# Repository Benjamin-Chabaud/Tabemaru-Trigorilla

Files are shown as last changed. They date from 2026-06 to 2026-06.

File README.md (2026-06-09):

# Tabemaru Control Board

## Overview
This repository contains the firmware (`tabemaru-V5-verbose.ino`) and documentation for the **Tabemaru Control Board**. The system is built around an Arduino Mega 2560 architecture (specifically using an Anycubic Trigorilla motherboard) combined with a custom PCB.

The system is designed to automate a sequence involving valves, a motor, and a heated bed, while continuously logging environmental data (temperature and humidity) to both a Serial Monitor and an SD Card in a non-blocking manner.

## Firmware Logic Explanation
The firmware is built using a non-blocking architecture, utilizing `millis()` to manage multiple tasks simultaneously without halting the processor. 

### 1. The Operational Sequence
The core logic of the machine relies on a 4-step state machine triggered by a hardware button (Button X-).
*   **Step 1 (Valve 1):** The sequence begins, the hotbed turns on, and Valve 1 opens for `1m 40s`.
*   **Step 2 (Motor):** Valve 1 closes, and the Motor runs for `5s`.
*   **Step 3 (Valve 2):** The motor stops, and Valve 2 opens for `2m 20s`.
*   **Step 4 (Wait & Hotbed):** Valve 2 closes. The system waits until the total elapsed time reaches `800s`. During this entire 800-second sequence, the heated bed actively regulates its temperature. Once 800 seconds pass, the sequence automatically terminates and resets.

*Note: All timings are defined as constants at the top of the code and can be easily modified.*

### 2. Hardware Interrupts
To ensure zero-latency responsiveness, the physical buttons do not use standard `digitalRead()` polling. Instead, they use Hardware Interrupts (`attachInterrupt`). 
*   **X- Button (Sequence Start/Stop):** Reacts instantly to start the sequence or act as an emergency stop.
*   **Z- Button (LED / SD Eject):** A short press toggles the internal LED. Holding the button for 1.5 seconds safely ejects the SD card (suspends writing) or remounts it.

### 3. SD Card & Data Storage
The system logs data in CSV format. It features a robust **Hot-Swap background task**. If the SD card is removed (or communication fails due to interference), the system will safely catch the error and attempt to re-initialize the SD card every 10 seconds. When the card is reinserted, data logging resumes automatically.

**SD Card Requirements & Formatting:**
For the SD card module to work reliably with the Arduino architecture, the following requirements MUST be met:
*   **Capacity:** 8GB is highly recommended for maximum stability (though up to 32GB SDHC is technically supported). SDXC cards (64GB+) will not work.
*   **File System:** The card MUST be formatted in **FAT32** (or FAT16). exFAT, NTFS, or APFS are not supported by the standard Arduino library.
*   **Formatting Tool & Deep Reset:** It is strongly advised to use the official SD Association's *SD Memory Card Formatter*. If the Arduino fails to initialize the card, a standard "Quick Format" is often not enough. You must select **"Overwrite Format"** (Full Format) to completely wipe the flash memory sectors and rebuild the file system from scratch.
*   **Partition Scheme:** The card's partition map MUST be **MBR (Master Boot Record)**. If the card was previously formatted on a Mac or newer OS as GPT (GUID Partition Table), the Arduino will fail to read it. To fix this, the partition table must be completely wiped (e.g., using `diskpart > clean` on Windows) before reformatting to FAT32.
*   **File Naming:** The system writes to `LOG.CSV`, strictly adhering to the legacy 8.3 filename convention.

**Data Storage Capacity & Retention:**
At the current logging rate (one entry every 2 seconds), the system generates approximately 1.2 GB of CSV data per year of continuous 24/7 operation. An 8GB SD card (the recommended maximum size for optimal compatibility) can hold data for **over 5 years** before running out of space. 

Depending on your operational needs, you can either:
*   Safely eject the SD card every few years to manually archive and delete the data.
*   Modify the logging function in the firmware to implement a rolling log (automatically deleting the oldest data when space runs out).

**Hardware & Operational Recommendations:**
*   **Logic Level Shifting:** The Arduino outputs 5V logic, but SD cards strictly require 3.3V. Ensure your SD card reader module has a built-in logic level converter chip and a 3.3V voltage regulator. Direct 5V connections will damage the SD card and cause instability.
*   **Cable Length & Interference:** The SPI protocol is highly susceptible to electromagnetic interference (EMI). Keep the SPI cables (MISO, MOSI, SCK) as short as possible and route them away from high-power cables (like the hotbed heater or motor).
*   **Flash Wear-Leveling:** Since the system writes data continuously (24/7), standard consumer SD cards may suffer from premature flash memory degradation. It is highly recommended to use a **"High Endurance"** SD card (typically used for dashcams or security cameras) designed for continuous write operations.

### 4. Environmental Monitoring & Thermostat
*   **DHT20 Sensors:** Two I2C temperature/humidity sensors are routed through a **TCA9548A Multiplexer**. They are polled every 2 seconds.
*   **Thermostat:** The system reads an NTC 100k thermistor connected to analog pin `A15` (Port T2) and uses the Steinhart-Hart equation to calculate temperature in Celsius. It maintains a target temperature of 105°C using a 1°C hysteresis.
*   **OLED Display:** A 128x32 OLED display provides real-time feedback on sequence state, actuator status, SD card health, and sensor readings.

---

## Custom PCB Analysis (KiCad)

The custom "Tabemaru control board" acts as an intermediate shield/routing board that neatly bridges the Trigorilla motherboard with the external peripherals, and also acts as a Human-Machine Interface (HMI).

### Schematic Details
1.  **I2C Multiplexer (TCA9548A):**
    *   Connectors `J1` and `J6` are designed to host a TCA9548A multiplexer breakout board. 
    *   The `sda` and `scl` lines from the Trigorilla input are fed into the multiplexer.
    *   The multiplexer outputs channels `sd1/sc1` and `sd2/sc2` to split the I2C bus, allowing two identical DHT20 sensors (which have the same hardcoded I2C address) to operate simultaneously.
2.  **DHT20 Sensor Headers:**
    *   `J2` and `J3` connect to the Top and Bottom DHT20 sensors. They receive the separated I2C channels from the multiplexer alongside VCC and GND.
3.  **Trigorilla Interconnect (`J4`):**
    *   This 6-pin connector bridges the custom PCB back to the main Trigorilla board. It carries the primary I2C bus (`sda`, `scl`), Ground, VCC, and the two button signals (`bp1`, `bp2`).
4.  **OLED Screen Header (`J5`):**
    *   This 10-pin header routes `VCC`, `GND`, `sda`, and `scl` directly to the OLED screen. Notes indicate that `sc1` and `sd1` are connected just to physically route them through the connector, though they are not utilized by the screen itself.
5.  **User Inputs (Buttons):**
    *   `SW1` and `SW2` are tactile push buttons that pull the `bp1` and `bp2` lines to Ground when pressed. These correspond to the X- and Z- endstop logic in the code.
6.  **Power Delivery & Decoupling:**
    *   Capacitors `C1`, `C2`, `C3`, `C4` are placed across the VCC and GND lines to stabilize the power delivery to the sensors and ICs, preventing voltage drops and filtering out electrical noise.

### PCB Layout Notes
*   The PCB is a two-layer board (Top Copper in Red, Bottom Copper in Blue). Both sides are identical and interconnected so that the connectors can be mounted on either side depending on the final position of the board inside the composter. Although this makes the routing technically less optimized (for instance, a VCC line making a half-loop is not ideal), it provides necessary mechanical flexibility for prototyping.
*   Thick traces are used for the main VCC and GND rails to ensure stable current delivery, while thinner traces are used for data lines (`sda`, `scl`).
*   The design elegantly centralizes all messy external wiring (buttons, screen, sensors) into a single, clean interface board that connects directly to the Trigorilla via the `J4` header.

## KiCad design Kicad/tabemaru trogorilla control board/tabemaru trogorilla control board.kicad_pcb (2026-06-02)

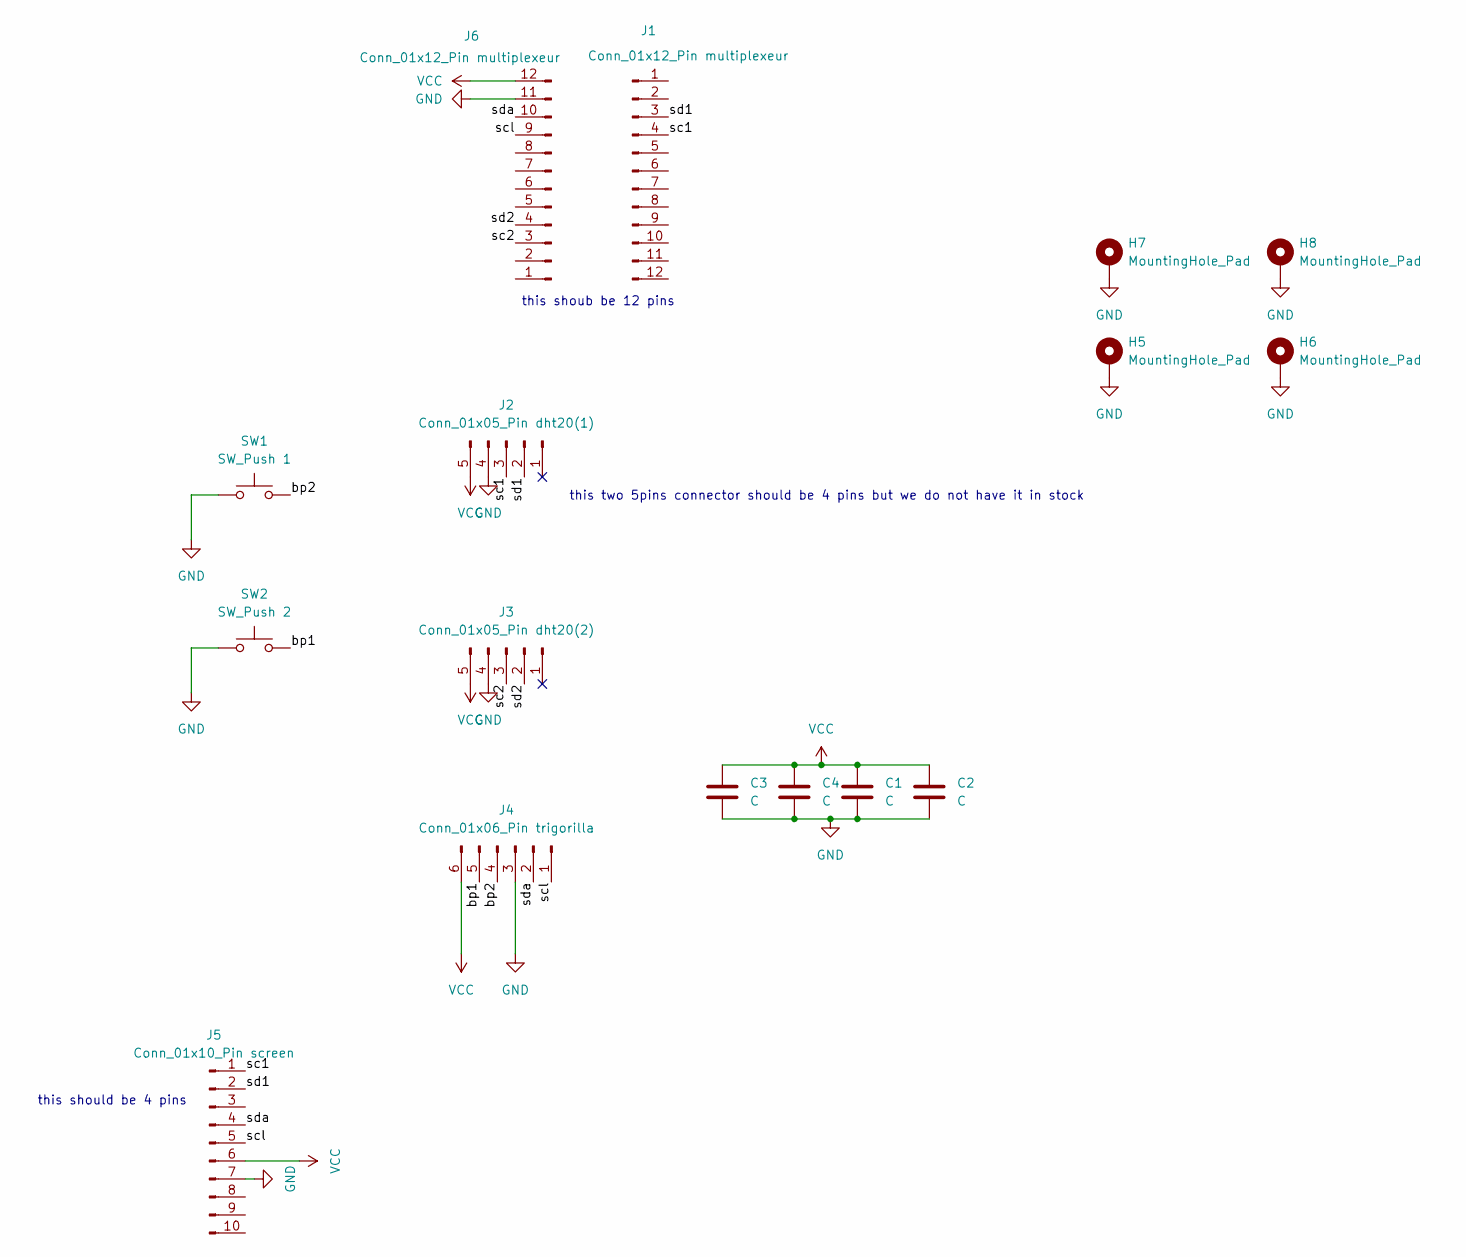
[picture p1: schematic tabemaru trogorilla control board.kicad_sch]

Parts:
C1, C2, C3, C4: C; PinHeader_1x02_P2.54mm_Vertical
H5, H6, H7, H8: MountingHole_Pad; MountingHole_3.5mm_Pad
J1, J6: Conn_01x12_Pin multiplexeur; PinHeader_1x12_P2.54mm_Vertical
J2: Conn_01x05_Pin dht20(1); JST_XH_B5B-XH-A_1x05_P2.50mm_Vertical
J3: Conn_01x05_Pin dht20(2); JST_XH_B5B-XH-A_1x05_P2.50mm_Vertical
J4: Conn_01x06_Pin trigorilla; JST_XH_B6B-XH-A_1x06_P2.50mm_Vertical
J5: Conn_01x10_Pin screen; PinHeader_1x10_P2.54mm_Vertical
SW1: SW_Push 1; SW_PUSH_6mm_H4.3mm
SW2: SW_Push 2; SW_PUSH_6mm_H4.3mm

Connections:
/bp1: J4.5, SW2.2
/bp2: J4.4, SW1.2
/sc1: J1.4, J2.3, J5.1
/sc2: J3.3, J6.3
/scl: J4.1, J5.5, J6.9
/sd1: J1.3, J2.2, J5.2
/sd2: J3.2, J6.4
/sda: J4.2, J5.4, J6.10
GND: C1.2, C2.2, C3.2, C4.2, H5.1 (1_1), H6.1 (1_1), H7.1 (1_1), H8.1 (1_1), J2.4, J3.4, J4.3, J5.7, J6.11, SW1.1, SW2.1
VCC: C1.1, C2.1, C3.1, C4.1, J2.5, J3.5, J4.6, J5.6, J6.12

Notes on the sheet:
this should be 4 pins
this shoub be 12 pins
this two 5pins connector should be 4 pins but we do not have it in stock

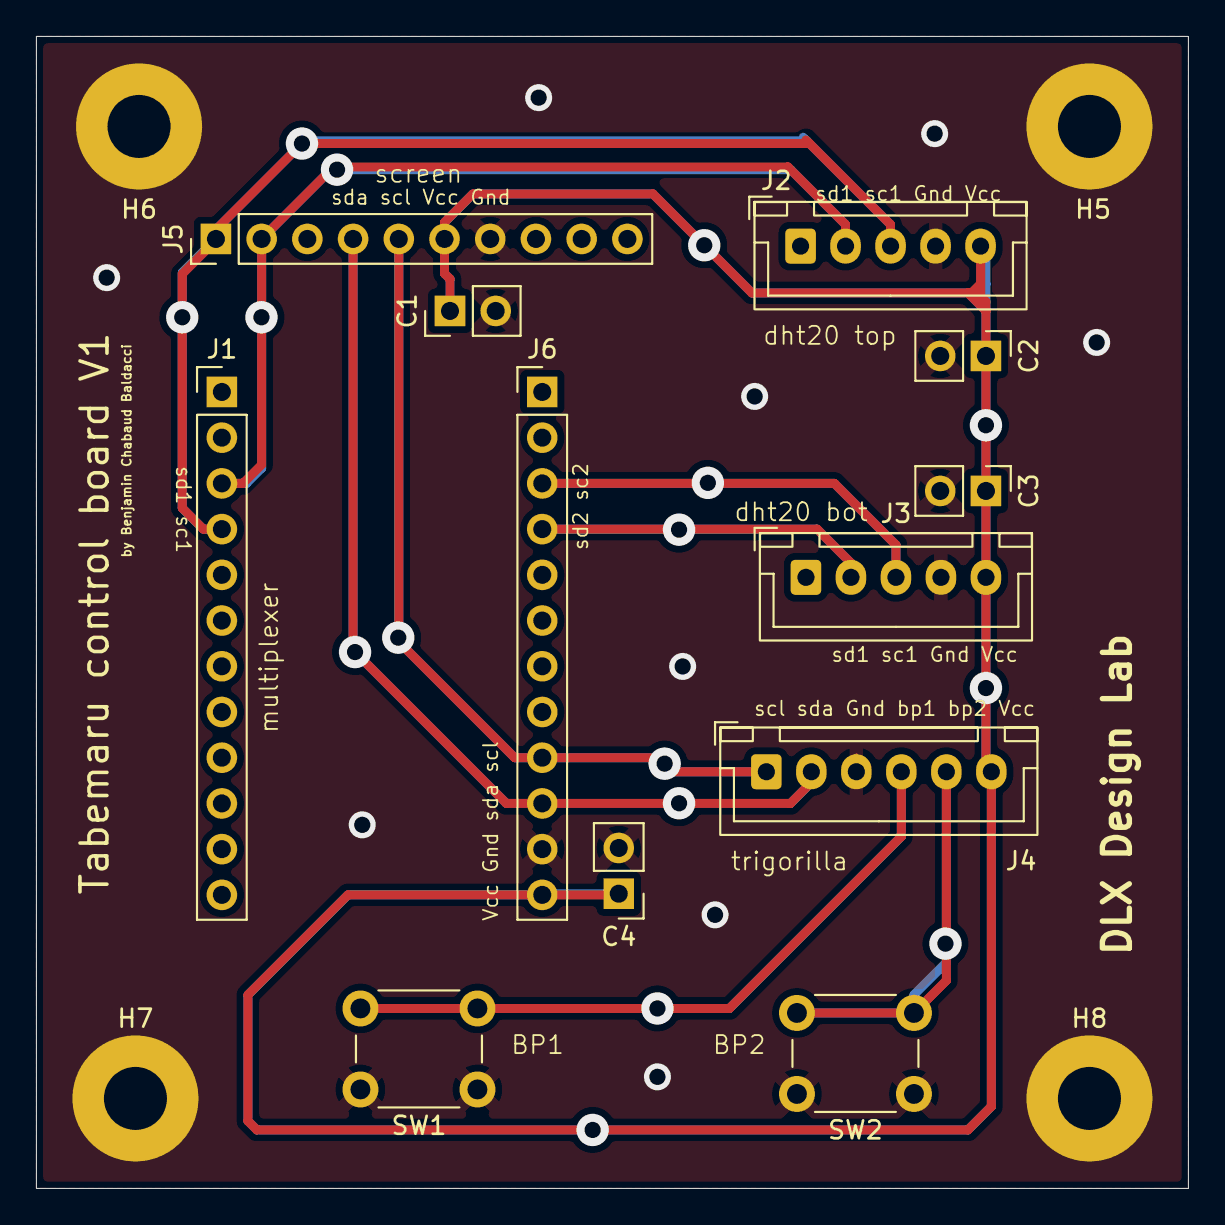
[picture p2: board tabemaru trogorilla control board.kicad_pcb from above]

Board: 2 copper layers, 64.0 x 64.0 mm, 16 parts (0 on the bottom side), 10 nets.

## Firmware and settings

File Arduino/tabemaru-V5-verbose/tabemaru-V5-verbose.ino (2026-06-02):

#include <Wire.h>
#include "DHT20.h"
#include <Adafruit_GFX.h>
#include <Adafruit_SSD1306.h>
#include <SPI.h>
#include <SD.h>

// --- SENSOR OBJECTS ---
// Two DHT20 temperature and humidity sensors
DHT20 dhtTop;
DHT20 dhtBot;

// --- I2C MULTIPLEXER (TCA9548A) CONTROL ---
// The multiplexer allows multiple I2C devices with the same address to coexist on the bus.
#define TCAADDR 0x70

// Function to switch the active channel on the I2C multiplexer
void tcaSelect(uint8_t i) {
  if (i > 7) return; // The TCA9548A only has 8 channels (0 to 7)
  Wire.beginTransmission(TCAADDR);
  Wire.write(1 << i);
  Wire.endTransmission();
  delay(10); // Short delay to ensure the switch is completed before communication
}

// --- OLED DISPLAY DEFINITIONS ---
#define SCREEN_WIDTH 128
#define SCREEN_HEIGHT 32
#define OLED_RESET    -1 // -1 means the display shares the Arduino reset pin
#define SCREEN_ADDRESS 0x3C // Default I2C address for 128x32 SSD1306 OLEDs
Adafruit_SSD1306 display(SCREEN_WIDTH, SCREEN_HEIGHT, &Wire, OLED_RESET);

// --- SD CARD DEFINITIONS ---
const int chipSelect = 53; // SPI Chip Select (CS) pin for the SD card reader on Trigorilla (Mega 2560)
bool sdReady = false;      // Flag indicating if the SD card is successfully initialized and ready
bool safeToEject = false;  // Flag indicating if the user requested to safely eject the SD card

// --- PIN DEFINITIONS (TRIGORILLA BOARD) ---
const int buttonXMinPin = 3;  // Sequence start button (connected to X- endstop pin)
const int buttonZMinPin = 18; // LED toggle and SD eject button (connected to Z- endstop pin)
const int motorPin  = 9;      // Motor control pin
const int valve1Pin = 7;      // First valve control pin
const int valve2Pin = 44;     // Second valve control pin
const int ledPin    = 10;     // Internal illumination LED control pin
const int hotbedPin = 8;      // Hotbed heating element control pin
const int bedTempPin = A15;   // Hotbed thermistor analog input pin (T2 port)

// --- TIMERS FOR NON-BLOCKING DELAYS ---
// We use millis() instead of delay() so the program never freezes
unsigned long previousLcdMillis = 0;
const long lcdInterval = 250;  // Refresh OLED every 250ms
unsigned long previousTempMillis = 0;
const long tempInterval = 500; // Read hotbed temperature every 500ms
unsigned long previousDHTMillis = 0;
const long dhtInterval = 2000; // Read DHT20 sensors every 2000ms (2 seconds)
unsigned long previousSDMillis = 0;
const long sdInterval = 10000; // Attempt SD card reconnection every 10 seconds

// --- SEQUENCE TIMINGS (in milliseconds) ---
const unsigned long timeValve1 = 100000; // Step 1: Valve 1 remains open for 1 minute and 40 seconds
const unsigned long timeMotor  = 5000;   // Step 2: Motor runs for 5 seconds
const unsigned long timeValve2 = 140000; // Step 3: Valve 2 remains open for 2 minutes and 20 seconds
const unsigned long timeHotbed = 800000; // Total hotbed activation time, which also dictates the end of the entire sequence

// --- STATE MEMORY ---
bool ledState = LOW;                  // Current state of the illumination LED
int sequenceState = 0;                // Current step of the operational sequence (0 = Idle, 1-4 = Active)
unsigned long sequenceStartTime = 0;  // Timestamp when the sequence was started

// --- HARDWARE INTERRUPT VARIABLES ---
// Using volatile variables because they are modified inside Interrupt Service Routines (ISRs)
volatile unsigned long xFallTime = 0;
volatile bool flagXPressed = false;   // Flag raised when the X button is pressed

volatile unsigned long zFallTime = 0;
volatile bool zCurrentlyPressed = false; // Real-time state of the Z button
volatile bool zStateChanged = false;     // Flag raised when the Z button state changes
bool longPressHandled = false;           // Prevents multiple triggers for a single long press
const unsigned long LONG_PRESS_TIME = 1500; // Holding Z button for 1.5 seconds triggers SD Eject

// Interrupt Service Routine for Button X (Sequence Start)
void isr_X() {
  if (millis() - xFallTime > 200) { // Software debounce: ignore signals closer than 200ms
    flagXPressed = true;
    xFallTime = millis();
  }
}

// Interrupt Service Routine for Button Z (LED Toggle / SD Eject)
void isr_Z() {
  bool st = digitalRead(buttonZMinPin);
  zCurrentlyPressed = (st == LOW); // LOW means the button is pressed (INPUT_PULLUP logic)
  if (zCurrentlyPressed) {
    zFallTime = millis(); // Record the exact time the button was pressed down
  }
  zStateChanged = true;
}

// --- THERMOSTAT VARIABLES ---
const float targetTemp = 105.0; // Target temperature for the hotbed in Celsius
const float hysteresis = 1.0;   // Allowable temperature drift before re-engaging the heater
bool regulateHotbed = false;    // Flag enabling the thermostat regulation logic
float currentBedTemp = 0.0;     // Last read temperature of the hotbed
bool isHeatingActive = false;   // Flag tracking if the heating element is currently ON

// Steinhart-Hart equation constants for 100k NTC Thermistor
const float R1 = 4700.0;   // Pull-up resistor on the Trigorilla board (4.7k Ohm)
const float R0 = 100000.0; // Nominal resistance of the thermistor at 25C (100k Ohm)
const float T0 = 298.15;   // Nominal temperature in Kelvin (25C)
const float B = 3950.0;    // Beta coefficient of the thermistor

// --- EVENT LOGGING FUNCTION ---
// Formats and outputs system state to both the Serial Monitor and the SD Card CSV file.
void logEvent(String eventName) {
  unsigned long currentMillis = millis();
  
  // Resolve boolean states for logging based on the current sequence step
  bool v1State = (sequenceState == 1);
  bool mState = (sequenceState == 2);
  bool v2State = (sequenceState == 3);
  bool hotbedState = (regulateHotbed && isHeatingActive);

  // 1. Output to Serial Monitor (Human-readable format)
  Serial.print("[LOG] Time: "); Serial.print(currentMillis);
  Serial.print(" | Event: "); Serial.print(eventName);
  Serial.print(" | Top: "); Serial.print(dhtTop.getTemperature(), 1); Serial.print("C/"); Serial.print(dhtTop.getHumidity(), 1); Serial.print("%");
  Serial.print(" | Bot: "); Serial.print(dhtBot.getTemperature(), 1); Serial.print("C/"); Serial.print(dhtBot.getHumidity(), 1); Serial.print("%");
  Serial.print(" | Bed: "); Serial.print(currentBedTemp, 1); Serial.print("C");
  Serial.print(" | SEQ: "); Serial.print(sequenceState);
  Serial.print(" | LED:"); Serial.print(ledState ? 1 : 0);
  Serial.print(" V1:"); Serial.print(v1State ? 1 : 0);
  Serial.print(" V2:"); Serial.print(v2State ? 1 : 0);
  Serial.print(" M:"); Serial.print(mState ? 1 : 0);
  Serial.print(" HB:"); Serial.println(hotbedState ? 1 : 0); 

  // 2. Output to SD Card (CSV format for data analysis)
  if (sdReady && !safeToEject) {
    File dataFile = SD.open("LOG.CSV", FILE_WRITE);
    if (dataFile) {
      dataFile.print(currentMillis); dataFile.print(",");
      dataFile.print(eventName); dataFile.print(",");
      dataFile.print(dhtTop.getTemperature(), 1); dataFile.print(",");
      dataFile.print(dhtTop.getHumidity(), 1); dataFile.print(",");
      dataFile.print(dhtBot.getTemperature(), 1); dataFile.print(",");
      dataFile.print(dhtBot.getHumidity(), 1); dataFile.print(",");
      dataFile.print(currentBedTemp, 1); dataFile.print(",");
      dataFile.print(sequenceState); dataFile.print(",");
      dataFile.print(ledState ? 1 : 0); dataFile.print(",");
      dataFile.print(v1State ? 1 : 0); dataFile.print(",");
      dataFile.print(v2State ? 1 : 0); dataFile.print(",");
      dataFile.print(mState ? 1 : 0); dataFile.print(",");
      dataFile.println(hotbedState ? 1 : 0); 
      
      dataFile.close();
    } else {
      // If the file fails to open, assume the SD card was abruptly removed
      sdReady = false;
      Serial.println("[CRITICAL ERROR] SD Card lost during event writing!");
    }
  }
}

// --- SETUP ROUTINE ---
// Runs once at power-on to initialize all hardware components.
void setup() {
  Serial.begin(115200);
  Serial.println("==================================");
  Serial.println("[SYSTEM] Booting up Tabemaru V5...");
  
  Serial.println("[SYSTEM] Initializing Actuator Pins...");
  // Configure output pins for relays, motor, and heating element
  pinMode(motorPin, OUTPUT);
  pinMode(valve1Pin, OUTPUT);
  pinMode(valve2Pin, OUTPUT);
  pinMode(ledPin, OUTPUT);
  pinMode(hotbedPin, OUTPUT);

  // Set initial safe states (everything OFF) without triggering log events yet
  regulateHotbed = false; 
  digitalWrite(hotbedPin, LOW); 
  digitalWrite(valve1Pin, LOW);
  digitalWrite(motorPin, LOW);
  digitalWrite(valve2Pin, LOW);
  sequenceState = 0; 
  isHeatingActive = false;
  
  digitalWrite(ledPin, LOW);

  // Configure input pins for buttons with internal pull-up resistors
  pinMode(buttonXMinPin, INPUT_PULLUP);
  pinMode(buttonZMinPin, INPUT_PULLUP);

  Serial.println("[SYSTEM] Attaching Hardware Interrupts...");
  // Attach interrupts for zero-latency button responses
  attachInterrupt(digitalPinToInterrupt(buttonXMinPin), isr_X, FALLING); // Triggers when pressed (HIGH to LOW)
  attachInterrupt(digitalPinToInterrupt(buttonZMinPin), isr_Z, CHANGE);  // Triggers on press and release

  Serial.println("[SYSTEM] Starting I2C Bus...");
  Wire.begin();
  
  // Initialize DHT20 Sensors through the multiplexer
  Serial.println("[SYSTEM] Initializing DHT20 Sensors...");
  tcaSelect(0); // Select multiplexer channel 0 for the top sensor
  if(dhtTop.begin()) { Serial.println("[SYSTEM] TOP DHT20 connected on SC0."); }
  else { Serial.println("[ERROR] TOP DHT20 failed to connect!"); }
  
  tcaSelect(3); // Select multiplexer channel 3 for the bottom sensor
  if(dhtBot.begin()) { Serial.println("[SYSTEM] BOTTOM DHT20 connected on SC3."); }
  else { Serial.println("[ERROR] BOTTOM DHT20 failed to connect!"); }
  
  // Initialize the OLED Display
  Serial.println("[SYSTEM] Initializing OLED Display...");
  if(!display.begin(SSD1306_SWITCHCAPVCC, SCREEN_ADDRESS)) {
    Serial.println("[ERROR] OLED Screen failed!");
  } else {
    display.clearDisplay();
    display.setTextSize(1);
    display.setTextColor(SSD1306_WHITE);
    display.setCursor(0,0);
    display.println("System Ready...");
    display.display();
    delay(500); // Briefly show the ready message
  }

  // Initialize the SD Card communication via SPI
  Serial.print("[SYSTEM] Initializing SD card...");
  pinMode(53, OUTPUT); // Hardware SS pin must be OUTPUT on Mega for SPI to work

  if (!SD.begin(chipSelect)) {
    Serial.println(" FAILED! (Will retry in background)");
    sdReady = false;
  } else {
    Serial.println(" OK!");
    sdReady = true;
    
    // Create or open the CSV file and write the header row if the file is new
    File dataFile = SD.open("LOG.CSV", FILE_WRITE);
    if (dataFile) {
      if (dataFile.size() == 0) {
        dataFile.println("Time_ms,Event,Top_Temp_C,Top_Hum_%,Bot_Temp_C,Bot_Hum_%,Bed_Temp_C,Sequence,LED_State,Valve1,Valve2,Motor,Hotbed");
      }
      dataFile.close();
      logEvent("SYSTEM_BOOT"); // Log the initial boot event
    }
  }
}

// --- STOP SEQUENCE FUNCTION ---
// Safely terminates any active sequence, turns off all actuators, and resets the state machine.
void stopSequence() {
  regulateHotbed = false; 
  digitalWrite(hotbedPin, LOW); 
  digitalWrite(valve1Pin, LOW);
  digitalWrite(motorPin, LOW);
  digitalWrite(valve2Pin, LOW);
  sequenceState = 0; 
  isHeatingActive = false;
  logEvent("SEQ_STOPPED");
}

// --- MAIN CONTROL LOOP ---
// Executes continuously, handling thermostats, buttons, sequence progression, sensors, and displays.
void loop() {
  unsigned long currentMillis = millis(); 

  // --- 0. THERMOSTAT MANAGEMENT ---
  // Evaluates the hotbed thermistor and regulates heating
  if (currentMillis - previousTempMillis >= tempInterval) {
    previousTempMillis = currentMillis;
    int rawValue = analogRead(bedTempPin);
    
    // Safety check: Detect disconnected (near 1023) or shorted (near 0) thermistor
    if (rawValue < 10 || rawValue > 1010) {
      if (regulateHotbed || currentBedTemp != -1.0) {
        digitalWrite(hotbedPin, LOW); // Force heater off for safety
        currentBedTemp = -1.0;        // Indicate error state
        if (regulateHotbed) {
          logEvent("HOTBED_ERROR");
          stopSequence();             // Abort sequence if heating fails
        }
      }
    } else {
      // Calculate temperature using the Steinhart-Hart equation
      float R2 = R1 * ((float)rawValue / (1023.0 - (float)rawValue));
      float tempKelvin = 1.0 / ( (1.0 / T0) + (1.0 / B) * log(R2 / R0) );
      currentBedTemp = tempKelvin - 273.15; // Convert Kelvin to Celsius

      // Thermostat Regulation Logic
      if (regulateHotbed) {
        // Turn ON if temperature drops below the target minus hysteresis
        if (currentBedTemp < (targetTemp - hysteresis) && !isHeatingActive) {
          digitalWrite(hotbedPin, HIGH); 
          isHeatingActive = true;
          logEvent("HOTBED_HEATING_ON");
        } 
        // Turn OFF if temperature reaches or exceeds the target
        else if (currentBedTemp >= targetTemp && isHeatingActive) {
          digitalWrite(hotbedPin, LOW); 
          isHeatingActive = false;
          logEvent("HOTBED_HEATING_OFF");
        }
      } else {
        // Ensure heater remains off if regulation is disabled
        if (isHeatingActive) {
           digitalWrite(hotbedPin, LOW);
           isHeatingActive = false;
           logEvent("HOTBED_HEATING_OFF_FORCED");
        }
      }
    }
  }

  // --- 1. X- BUTTON CHECK (START/STOP SEQUENCE) ---
  // Evaluates the flag raised by the hardware interrupt
  if (flagXPressed) {
    flagXPressed = false; // Acknowledge the press
    logEvent("BUTTON_X_PRESSED");
    
    // If system is idle, start the sequence
    if (sequenceState == 0) {
      sequenceState = 1;
      sequenceStartTime = currentMillis; 
      regulateHotbed = true;         // Start heating the bed
      digitalWrite(valve1Pin, HIGH); // Open the first valve
      logEvent("SEQ_START_STEP1_V1_ON");
    } else {
      // If sequence is already running, pressing X acts as an Emergency Stop
      stopSequence();
    }
  }

  // --- 2. Z- BUTTON CHECK (LED TOGGLE & SD EJECT) ---
  // Evaluates real-time state updated by the hardware interrupt
  if (zCurrentlyPressed) {
    // Check if the button has been held down long enough to trigger SD Eject
    if ((currentMillis - zFallTime >= LONG_PRESS_TIME) && !longPressHandled) {
      safeToEject = !safeToEject; // Toggle ejection state
      
      if (safeToEject) {
        sdReady = false; // Disconnect software link to SD
        Serial.println("\n[SYSTEM] *** SD CARD SAFELY EJECTED ***");
        logEvent("SD_EJECT_COMMAND"); // Logs to serial only, as sdReady is now false
      } else {
        Serial.println("\n[SYSTEM] *** SD CARD MOUNT COMMAND ***");
        logEvent("SD_MOUNT_COMMAND");
      }
      longPressHandled = true; // Prevent re-triggering until button is released
    }
  } else {
    // Button has been released
    if (zStateChanged) {
      zStateChanged = false; // Acknowledge the release
      
      // If it was a short press (less than LONG_PRESS_TIME but more than 50ms for debounce), toggle LED
      if (!longPressHandled && (currentMillis - zFallTime > 50)) {
        ledState = !ledState; 
        digitalWrite(ledPin, ledState ? HIGH : LOW);
        logEvent(ledState ? "LED_ON" : "LED_OFF");
      }
      longPressHandled = false; // Reset the long press tracker
    }
  }

  // --- 3. SEQUENCE PROGRESSION LOGIC ---
  // Automatically advances the sequence based on elapsed time
  if (sequenceState > 0) {
    unsigned long elapsed = currentMillis - sequenceStartTime;
    
    // Step 1: Valve 1 remains open for timeValve1
    if (sequenceState == 1 && elapsed >= timeValve1) {
      digitalWrite(valve1Pin, LOW);  // Close Valve 1
      digitalWrite(motorPin, HIGH);  // Start Motor
      sequenceState = 2;
      logEvent("SEQ_STEP2_V1_OFF_M_ON");
    }
    // Step 2: Motor runs for timeMotor
    else if (sequenceState == 2 && elapsed >= (timeValve1 + timeMotor)) { 
      digitalWrite(motorPin, LOW);   // Stop Motor
      digitalWrite(valve2Pin, HIGH); // Open Valve 2
      sequenceState = 3;
      logEvent("SEQ_STEP3_M_OFF_V2_ON");
    }
    // Step 3: Valve 2 remains open for timeValve2
    else if (sequenceState == 3 && elapsed >= (timeValve1 + timeMotor + timeValve2)) { 
      digitalWrite(valve2Pin, LOW);  // Close Valve 2
      sequenceState = 4;
      logEvent("SEQ_STEP4_V2_OFF_WAIT"); // Wait state while hotbed continues heating
    }
    // Step 4: System waits until timeHotbed is reached, then terminates
    else if (sequenceState == 4 && elapsed >= timeHotbed) { 
      logEvent("SEQ_FINISHED");
      stopSequence();
    }
  }

  // --- 4. DUAL DHT20 SENSOR POLLING ---
  if (currentMillis - previousDHTMillis >= dhtInterval) {
    previousDHTMillis = currentMillis; 
    
    tcaSelect(0); dhtTop.read(); // Read top sensor via multiplexer channel 0
    tcaSelect(3); dhtBot.read(); // Read bottom sensor via multiplexer channel 3

    logEvent("PERIODIC_LOG"); // Log all environmental data to Serial and SD
  }
  
  // --- 5. OLED DISPLAY UPDATE ---
  if (currentMillis - previousLcdMillis >= lcdInterval) {
    previousLcdMillis = currentMillis;
    
    // Determine active actuator states for display
    bool v1State = (sequenceState == 1);
    bool mState = (sequenceState == 2);
    bool v2State = (sequenceState == 3);

    // Determine string representation of the hotbed status
    String bedStatus = "";
    if (currentBedTemp == -1.0) bedStatus = "ERR";
    else if (regulateHotbed && isHeatingActive) bedStatus = "HEAT";
    else if (regulateHotbed && !isHeatingActive) bedStatus = "HOLD";
    else bedStatus = "OFF";

    display.clearDisplay();
    display.setTextSize(1);
    display.setTextColor(SSD1306_WHITE);
    
    // Row 1: System Status
    display.setCursor(0,0);
    display.print("SEQ:"); display.print(sequenceState); 
    display.print(" L:"); display.print(ledState ? "ON " : "OFF");
    display.print(" SD:"); 
    if (safeToEject) display.println("EJ");
    else if (sdReady) display.println("OK");
    else display.println("NO");

    // Row 2: Actuator Status
    display.setCursor(0,8);
    display.print("V1:"); display.print(v1State ? "ON " : "OFF ");
    display.print("V2:"); display.print(v2State ? "ON " : "OFF ");
    display.print("M:");  display.println(mState ? "ON" : "OFF");

    // Row 3: Environmental Data (Alternates between Top and Bottom sensors every 5 seconds)
    display.setCursor(0,16);
    bool showTopData = (currentMillis / 5000) % 2 == 0;
    if (showTopData) {
      display.print("AirT:"); display.print(dhtTop.getTemperature(), 1);
      display.print("C H:"); display.print(dhtTop.getHumidity(), 0); display.println("%");
    } else {
      display.print("AirB:"); display.print(dhtBot.getTemperature(), 1);
      display.print("C H:"); display.print(dhtBot.getHumidity(), 0); display.println("%");
    }

    // Row 4: Hotbed Status
    display.setCursor(0,24);
    display.print("Bed: ");
    if(currentBedTemp == -1.0) display.print("ERR");
    else display.print(currentBedTemp, 0);
    display.print("C ["); display.print(bedStatus); display.print("]");

    display.display();
  }

  // --- 6. SD CARD RECONNECTION (HOT-SWAP BACKGROUND TASK) ---
  if (currentMillis - previousSDMillis >= sdInterval) {
    previousSDMillis = currentMillis;

    // Only attempt reconnection if the user hasn't explicitly ejected the card
    if (!safeToEject) {
      if (!sdReady) {
        Serial.println("[SYSTEM] SD Card missing. Attempting to reconnect...");
        digitalWrite(chipSelect, HIGH); // Pulse CS to reset SPI state
        delay(1);
        if (SD.begin(chipSelect)) {
          sdReady = true;
          Serial.println("[SYSTEM] SD Card RECONNECTED successfully.");
          logEvent("SD_RECONNECTED");
        } else {
          Serial.println("[ERROR] SD Card reconnection FAILED.");
        }
      }
    }
  }
}
